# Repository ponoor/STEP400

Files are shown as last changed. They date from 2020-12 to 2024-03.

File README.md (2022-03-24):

## STEP400
STEP400

STEP400 is a 4-axis stepper motor driver designed for art or design projects. STEP400 combines the following elements into one single board:

- [Arduino Zero](https://www.arduino.cc/en/Guide/ArduinoZero)
- Ethernet shield
- Four stepper motor drivers
- Sensor inputs for homing and limiting

The [current firmware](https://github.com/ponoor/step-series-universal-firmware) is focused on working with [Open Sound Control](http://opensoundcontrol.org/) (OSC) via Ethernet, which is a common protocol for creative coding environments, like openFrameworks, Processing, Max, Unity, or Touch Designer.

Stepper driver chips are STMicroelectronics's [powerSTEP01](https://www.st.com/en/motor-drivers/powerstep01.html) which provide most of functionalities as a stepper driver.

Friend of STEP400 : [STEP800](https://github.com/ponoor/STEP800)

## Store
https://ponoor.com/en/shop/

## Documentation
https://ponoor.com/en/docs/step-series/

Forum: https://github.com/ponoor/step-series-support/discussions

## Repository Contents
### Firmware
**Important Note:**
The latest firmware is available at [STEP-series Universal Firmware](https://github.com/ponoor/step-series-universal-firmware) repository. Following directories and Releases are not maintained anymore. 

- [/STEP400_firmware](https://github.com/ponoor/STEP400/tree/master/STEP400_firmware) : Arduino Sketch folder
- [/firmware-platformio/STEP400_firmware](https://github.com/ponoor/STEP400/tree/master/firmware-platformio/STEP400_firmware) : PlatformIO folder

### Hardware
[/hardware](https://github.com/ponoor/STEP400/tree/master/hardware) : Eagle design files, BOM lists, and schematics PDFs

### Others
[/configTool](https://github.com/ponoor/STEP400/tree/master/configTool) : The configuration tool consists of a html and JavaScritpts.

## Firmware dependency
- **[OSC Library](https://github.com/CNMAT/OSC)** from CNMAT
- **[Ponoor PowerSTEP01 Library](https://github.com/ponoor/Ponoor_PowerSTEP01_Library)**
- **[ArduinoJSON Library](https://arduinojson.org/)**
- **[Adafruit SleepyDog Arduino Library](https://github.com/adafruit/Adafruit_SleepyDog)**

## Examples
### Max
https://github.com/ponoor/step-series-example-Max

### Processing
https://github.com/yuskegoto/STEP400_Processing

Contribution of [@yuskegoto](https://github.com/yuskegoto)

### openFrameworks
https://github.com/ponoor/step-series-example-openFrameworks

Contribution of [@niimi](https://github.com/niimi)

### Unity
https://github.com/ponoor/step-series-example-Unity

Contribution of [@niimi](https://github.com/niimi)

### TouchDesigner
https://github.com/ponoor/step-series-example-TouchDesigner

Contribution of [@loveandsheep](https://github.com/loveandsheep) and [@yuskegoto](https://github.com/yuskegoto)

### Node-RED
https://github.com/yuskegoto/STEP400_Node-RED

Contribution of [@yuskegoto](https://github.com/yuskegoto)

### Python library
https://github.com/ponoor/python-step-series

Contribution of [@JulianOrteil](https://github.com/JulianOrteil)

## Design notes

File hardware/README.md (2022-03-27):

# Diagram
```mermaid
flowchart LR
	MCU ---|SPI/SERCOM4| W5500 --- Ethernet
	MCU --- |SPI/SERCOM3|PowerSTEP01 --> Motor
	HomeSw -->|SW| PowerSTEP01
	LimitSw -->|ADCIN| PowerSTEP01
	DIPSW --> MCU
	MCU --> Brake
  ```
  
  Check the [document](https://ponoor.com/en/docs/step-series/technical-information/hardware-step400/) for details.

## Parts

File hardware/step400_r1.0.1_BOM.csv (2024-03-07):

# | Name | Value | Description | Package | Manufacture | Manufacturer Part Number | Designator | Qty | Type
1 | SMD-LED | GREEN | general LED green | LED-0603 | Lite-On | LTST-C193TGKT-5A | 3.3V, BUSY1, BUSY2, BUSY3, BUSY4 | 5 | SMD
2 | MLCC | 4.7uF/100V | 4.7uF / 20% / 100V / X5R | C1210 | Taiyo Yuden | HMK325C7475KMHPE | C1, C2 | 2 | SMD |  | updated
3 | MLCC | 47uF/6.3V | 47uF / 20% / 6.3V / X5R | C1206 | Samsung Electro-Mechanics | CL31A476MQHNNNE | C11, C12, C25, C26 | 4 | SMD |  | updated
4 | MLCC | 10uF/10V | 10uF / 20% / 10V / X5R | C0805 | Samsung Electro-Mechanics | CL21A106KOQNNNG | C14 | 1 | SMD
5 | MLCC | 1uF/6.3V | 1uF / 20% / 6.3V / X5R | C0603 | Samsung Electro-Mechanics | CL10A105KO8NNNC | C17, C18, C19, C20, C39, C40, C69, C70 | 8 | SMD
6 | MLCC | 4.7uF/6.3V | 4.7uF / 20% / 6.3V / X5R | C0603 | Samsung Electro-Mechanics | CL10A475KQ8NNNC | C29 | 1 | SMD
7 | MLCC | 100nF/100V | 100nF / 20% / 100V / X5R | C0805 | Samsung Electro-Mechanics | CL21B104KCFNNNE | C3, C57, C58, C87, C88 | 5 | SMD
8 | MLCC | 10nF/25V | 10nF / 20% / 25V / X5R | C0402 | Walsin Tech Corp | 0402B103K250 | C30, C35 | 2 | SMD
9 | MLCC | 22nF 50V | 22nF / 20% / 50V / X5R | C0402 | Walsin Tech Corp | 0402F223Z500CT | C34 | 1 | SMD
10 | MLCC | 6.8nF/25V | 6.8nF / 20% / 25V / X5R | C0402 | Walsin Tech Corp | 0402B682K500CT | C36, C37 | 2 | SMD
11 | MLCC | 100nF/50V | 100nF / 20% / 50V / X5R | C0603 | Walsin Tech Corp | 0603B104K500CT | C4, C8 | 2 | SMD
12 | MLCC | 47nF/50V | 47nF / 20% / 50V / X5R | C0805 | YAGEO | CC0805KRX7R9BB473 | C41, C42, C71, C72 | 4 | SMD |  | updated
13 | MLCC | 220nF/100V | 220nF / 20% / 100V / X5R | C0805 | YAGEO | CC0805KKX7R0BB224 | C43, C44, C47, C48, C49, C50, C51, C53, C73, C74, C77, C78, C79, C80, C81, C83 | 16 | SMD |  | updated
14 | MLCC | 100nF / 25V | 100nF / 20% / 25V / X5R | C0402 | Samsung Electro-Mechanics | CL05A104KA5NNNC | C5, C9, C10, C13, C15, C16, C21, C22, C23, C24, C27, C28, C31, C38, C45, C46, C55, C56, C75, C76, C85, C86 | 22 | SMD |  | updated
15 | MLCC | 470nF/25V | 470nF / 20% / 25V / X5R | C0603 | Samsung Electro-Mechanics | CL10B474KA8NNNC | C52, C54, C61, C62, C82, C84, C91, C92 | 8 | SMD
16 | Chemical Capacitor | 100uF/100V | 100uF / 20% / 100V | E5-10,5 | Rubycon | 100PX100MEFC10X16 | C59, C60, C63, C64, C89, C90, C93, C94 | 8 | THT
17 | MLCC | 22pF/50V | 22pF / 10% / 50V / X5R | C0402 | Walsin Tech Corp | 0402N220J500 | C6, C7, C32, C33 | 4 | SMD
18 | MLCC | 220nF/6.3V | 220nF / 20% / 6.3V / X5R | C0402 | YAGEO | CC0402KRX5R5BB224 | C65, C66, C95, C96 | 4 | SMD |  | updated
19 | MLCC | 22uF/6.3V | 22uF / 20% / 6.3V / X5R | C0805 | Samsung Electro-Mechanics | CL21A226MQQNNNE | C67, C68, C97, C98 | 4 | SMD
20 | Shrouded header | 2.5mm, 3P | B3B-XASK-1 | B3B-XASK-1 | JST | B03B-XASK-1(LF)(SN) | CN1, CN2, CN3, CN4, CN5, CN6, CN9, CN10 | 8 | THT
21 | Shrouded header | 2.5mm, 4P | B4B-XASK-1 | B4B-XASK-1 | JST | B04B-XASK-1(LF)(SN) | CN7, CN8, CN11, CN12 | 4 | THT | NO mount
22 | Zener Diode | 5.6V, 300mW | 5.6V ±7% 300mW | SOD-323 | ON Semiconductor | MM3Z5V6T1G | D1 | 1 | SMD
23 | Schottky diode | 100V 2A | 100V, 2A | DO-214AC | Guangdong Hottech | SS210A | D2 | 1 | SMD
24 | Switching diode array | BAR43 | 30V, 100mA | SOT23-3 | STMicroelectronics | BAR43SFILM | D3, D4, D5, D6 | 4 | SMD
25 | SMD-LED | Red | general LED red | LED-0603 | Lite-On | LTST-C193KRKT-5A | FLAG1, FLAG2, FLAG3, FLAG4, TX | 5 | SMD
26 | Ethernet Controller |  |  | TQFP48 | WIZnet | W5500 | IC1 | 1 | SMD
27 | DIP Switch |  | 8 digits | 2.54mm pitch SMD | kangshen | DSIC08LSGET | ID | 1 | SMD |  | updated
28 | DC Power receptacle |  | DC Power Receptacle Jack 5A 2.0mm 6.2mm | POWERJACK_SLOT | XKB Connectivity | DC-005-5A-2.0 | J1 | 1 | SMD
29 | Micro SD card slot |  |  |  | XUNPU | TF-115K | J2 | 1 | SMD
30 | 3.81mm 4pin header |  |  |  | Ningbo Kangnex Elec | WJ15EDGVC-3.81-4P | J3, J4, J5, J6 | 4 | THT
31 | Box header |  | Header 6P 0.100"(2.54mm) 2 | 61200621621 | Ckmtw(Shenzhen Cankemeng) | C132438 | J7 | 1 | THT
32 | SMD-LED | Orange | general LED orange | LED-0603 | Lite-On | LTST-C191KFKT | L | 1 | SMD
33 | Power Inductor | 15uH | ±20% 1.9A | L5050 | cjiang (Changjiang Microelectronics Tech) | FNR5040S150MT | L1 | 1 | SMD |  | updated
34 | Ferrite Beads | 330R-1500MA | 330Ω @ 100MHz 1.5A | L0805 | Murata Electronics | BLM21PG331SN1D | L2, L3 | 2 | SMD
35 | P-MOSFET |  | 100V 46A | D-PAK(TO252AA) | Winsok Semicon | WSF45P10 | Q1 | 1 | SMD
36 | Crystal Resonators | 32.768kHz | CRYSTAL | SMD-3215_2P | Seiko | SC-32S32.768kHz20PPM6pF | Q2 | 1 | SMD |  | updated
37 | Crystal Oscillator |  | 16MHz ±100ppm 3.3V | SG5032 | Shenzhen SCTF Elec | S5D16.000000B20F30T | Q3 | 1 | SMD |  | updated
38 | Chip Resistor | 100k | 5% 1/10W | R0603 | YAGEO | RC0603JR-07100KL | R1 | 1 | SMD
39 | Chip Resistor | 12.4K | 1％ 1/10W | R0603 | BOURNS | CR0603-FX-1242ELF | R11 | 1 | SMD |  | updated
40 | Chip Resistor | 1M 1/10W | 5% 1/10W | R0603 | YAGEO | AC0603JR-071ML | R13 | 1 | SMD
41 | Chip Resistor | 10R | 5% 1/10W | R0603 | YAGEO | RC0603JR-0710RL | R14 | 1 | SMD
42 | Chip Resistor | 330R | 5% 1/10W | R0603 | YAGEO | RC0603JR-07330RL | R15, R16 | 2 | SMD
43 | Chip Resistor | 0.1 | 1% 3W | R2512 | Bourns | CRA2512-FZ-R100ELF | R19, R20, R21, R22, R25, R26, R27, R28 | 8 | SMD
44 | Chip Resistor | 4.7k | 5% 1/10W | R0603 | YAGEO | AC0603JR-074K7L | R2 | 1 | SMD
45 | Chip Resistor | 5.1k | ±0.5% 0.1W | R0603 | YAGEO | RC0603FR-075K1L | R29, R30 | 2 | SMD
46 | Chip Resistor | 13k | 1％ 1/10W | R0603 | YAGEO | RC0603FR-0713KL | R3 | 1 | SMD
47 | Chip Resistor | 10K 1/10W | 5% 1/10W | R0603 | YAGEO | RC0603JR-0710KL | R4, R12, R31, R32, R33, R34 | 6 | SMD
48 | Chip Resistor | 3k | 1％ 1/10W | R0603 | YAGEO | RC0603FR-073KL | R5 | 1 | SMD
49 | Chip Resistor | 750 | 1％ 1/10W | R0603 | YAGEO | AC0603DR-07750RL | R6 | 1 | SMD
50 | Chip Resistor | 100R | 5% 1/10W | R0603 | YAGEO | RC0603JR-07100RL | R7, R8, R9, R10, R17, R18, R23, R24 | 8 | SMD
51 | Tactile Switch |  | SWITCH-SPST | 4.6x3.2 | ALPS Electric | SKRPABE010 | RESET | 1 | SMD
52 | Array Chip Resistor | 330 | 5% 1/16W | R0603 x4 | Bourns | CAY16-331J4LF | RN1, RN4, RN5 | 3 | SMD
53 | Array Chip Resistor | 33 | 5% 1/16W | R0603 x4 | Bourns | CAY16-330J4LF | RN2 | 1 | SMD
54 | Array Chip Resistor | 49.9 | 1% 1/16W | R0603 x4 | Bourns | CAY16-49R9F4LF | RN3 | 1 | SMD
55 | SMD-LED | Yellow | general LED yellow | LED-0603 | Lite-On | LTST-C191KSKT | RX | 1 | SMD
56 | Pin Header | 10 pin | Cortex Debug Connector | 1.27mm Pin Header 10P | Amphenol ICC | 20021121-00010C4LF | SWD | 1 | SMD
57 | TVS Diode Array | USBLC6-2SC6 | STMicroelectronics USBLC6 | SOT23-6L | STMicroelectronics | USBLC6-2SC6 | U1 | 1 | SMD
58 | DC-DC converter |  |  | HTSOP-J8 | ROHM | BD9G341AEFJ-E2 | U2 | 1 | SMD
59 | Voltage Regulator | LD1117S33 | 3.3V 0.8A | SOT223 | STMicroelectronics | LD1117S33TR | U3 | 1 | SMD
60 | MCU |  |  | TQFP-48 | Microchip | ATSAMD21G18A-AU | U4 | 1 | SMD
61 | Stepper Motor Driver |  |  | VFQFPN89 | STMicroelectronics | POWERSTEP01TR | U5, U6, U7, U8 | 4 | SMD
62 | USB Type C Connector |  | USB - Type C Female 16 SMT | USB-C_USB2.0-TYPE-C | XKB Connectivity | U262-161N-4BVC11 | USB1 | 1 | THT
63 | Barrier Terminal Block | 7.62mm, 2P |  | 7.62mm | Ningbo Kangnex Elec | WJ25C-B-7.62-2P | X1 | 1 | SMD
64 | Crystal Resonators | 25MHz | 25MHz ±20ppm12pF | CRYSTAL-3225 | Yangxing Tech | X322525MOB4SI | X2 | 1 | SMD |  | updated
65 | RJ45 Jack with Magnetics |  |  |  | Hanrun | HR871181A | X3 | 1 | THT

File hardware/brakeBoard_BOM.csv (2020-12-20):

# | Name | Value | Description | Package | Manufacture | MPN | Designator | Qty | Type
1 | SMD-LED | Red | general LED red | LED-0603 | Lite-On | LTST-C193KRKT-5A | D1, D10, D11, D12, D13 | 5 | SMD
2 | Schottky diode | 100V 2A |  | DO-214AC | Guangdong Hottech | SS210A | D2, D3, D4, D5, D6, D7, D8, D9 | 8 | SMD
3 | DC Power receptacle |  | DC Power Receptacle Jack 5A 2.0mm 6.2mm |  | XKB Connectivity | DC-005-5A-2.0 | J1 | 1 | THT
4 | PCB Header | 2P, Vertical | WR-TBL Serie 321 - 3.81 mm Vertical PCB Header | P=3.81mm | Ningbo Kangnex Elec | WJ15EDGVC-3.81-2P | J2, J3, J4, J5, J6 | 5 | THT
5 | Box header |  | Header 6P 0.100"(2.54mm) 2 | 61200621621 | Ckmtw(Shenzhen Cankemeng) | C132438 | J7 | 1 | THT
6 | N-MOSFET |  | 60V 28A(Tc) 3V @ 250uA 40mΩ @ 12A,10V | TO-252-2(DPAK) | Winsok Semicon | WSF28N06 | Q1, Q2, Q3, Q4 | 4 | SMD
7 | Chip Resistor | 5.6k | 5% 0.25W | R0805 | KOA Speer Elec | RK73B2ATTD562J | R1, R2, R3, R4, R5 | 5 | SMD
8 | Array Chip Resistor | 10 | 5% 1/16W | R0603 x4 | Bourns | CAY16-100J4LF | RN1 | 1 | SMD
9 | Array Chip Resistor | 10k | 5% 1/16W | R0603 x4 | Bourns | CAY16-103J4LF | RN2 | 1 | SMD

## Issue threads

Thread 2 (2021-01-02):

[Docs] Tutorial

kanta, 2021-01-02:
https://ponoor.com/en/docs/step400/tutorial/
プロトタイプからコネクタが変更になったことに合わせて、日本語版で下記部分を変更しました。また僕のほうで英文を入れてみています。

旧
STEP400の電源コネクタは大容量の電源を接続することを想定していますが、小さなモータを回す場合は下の写真のような変換コネクタを使ってACアダプタを接続すると便利です。このコネクタは電子パーツ店やAmazonなどで入手可能です。上の例に出てきたモータを1台回す場合は、ACアダプタの容量は24V1Aあれば十分です。

写真では両端に専用の端子を圧着して使っていますが、両端を剥いてはんだを流しただけの状態でも使用可能です。

新
上の例に出てきたモータを1台回す場合は、ACアダプタの容量は24V1Aあれば十分です。STEP400に接続可能なのは、外径5.5mm, 内径2.1mmでセンタープラスのACアダプタです。

If you want to run a single motor in the example above, the AC adapter’s capacity of 24V1A is sufficient. Applicable AC adapters are which have 5.5mm outer diameter / 2.1mm inner diameter / center positive connector.

そのほか、以下の英文を追加しています（堀尾訳、要修正です）。

To simplify this tutorial, we will assume that the PC and the board are connected peer to peer with Ethernet cable. You can of course also go through a network switch (NOT a router) instead. Routers can make things complicated when they have DHCP functionality, not recommended to get started.

You can set individual KVALs for example with `/setRunKval` for `KVAL_RUN` but we are going to try following command which can set 4 KVALs at once.

kanta, 2021-01-02:
とりあえず上記の文章は、未チェック英文のメモです！

yuskegoto, 2021-01-18:
DCバレルジャック／プラグは英語でもDC barrel jack / plug なので、そのようにしては。またApplicableはあまり自然はない気がしますので power supply must have .... としてみました。以下のような感じでいかがでしょうか？
If you want to run a single motor in the example above, the AC adapter’s capacity of 24V1A is sufficient. **The power supply** must have **DC barrel plug** with 5.5mm outer diameter / 2.1mm inner diameter / center positive.

kanta, 2021-01-18:
ありがとうございます！更新しました。
https://ponoor.com/en/docs/step400/tutorial/

Closed 2021-04-10.

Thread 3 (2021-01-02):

[Docs] Power supply and Motor

kanta, 2021-01-02:
旧
ターミナルには4つのねじ式端子があり、左手の2個がマイナス、右手の2個がプラスの端子です。

新
STEP400にはDCジャック(4)と、ねじ式端子(5)の2種類の電源端子があります。
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
DCジャックは
- 外径5.5mm
- 内径2.1mm
- センタープラス

のコネクタが適合します。DCジャックの定格は24V5Aです。それを超える電圧および電流で使用する場合は、ねじ式ターミナルを使用してください。

ねじ式ターミナルは、基板端面から見て左がマイナス、右側がプラスの端子です。各端子のねじ径はM3です。直接ケーブルの芯線を締めこむこともできますが、専用の端子を使うとより確実に接続できます。

---

There are 2 types of power input ternaminals on STEP400, a DC jack (4) and a screw terminal(5).
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

For the DC jack, a connector which has
- 5.5mm outer diameter
- 2.1mm inner diameter
- center positive

will be applicable. The rateing of the DC jack are limited to 24V/5A. Use the screw terminal if you want to apply bigger voltage or current than that.

For the screw terminal, if you see the connector from the edge of the board, left side is negative, right side is positive terminal. The screw diameter is M3. You can fasten the cupper wire directly, but you can also use a dedicated terminal for a more secure connection.

yuskegoto, 2021-01-18:
以下のようにしてはいかがでしょうか？
For the DC barrel plug, use a DC barrel plug with following specifications

- 5.5mm outer diameter
- 2.1mm inner diameter
- center positive

The rating of the DC jack are limited to 24V/5A. Use the screw terminal if you want to supply larger voltage or current.

kanta, 2021-01-18:
こちらも #2 でご指摘いただいた部分のバリエーションですね。こういう細かな部分まで見ていただいてとても助かります！ありがとうございます。こちらもアップデートしましたー。

Closed 2021-04-10.

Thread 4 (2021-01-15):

[Docs] 電流モード、電圧モードを切り替えるコマンドがない

kanta, 2021-01-15:
[KVALとTVAL](https://ponoor.com/docs/step400/osc-command-reference/kval-and-tval/) というページに追記して、「電圧モードと電流モード」などに改題し要と思います。

kanta, 2021-01-15:
更新しました。
https://ponoor.com/docs/step400/functional-description/voltage-mode-and-current-mode/
https://ponoor.com/en/docs/step400/osc-command-reference/kval-and-tval/

Closed 2021-01-18.

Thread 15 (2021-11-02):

Python Library for Ponoor

JulianOrteil, 2021-11-02:
Good day @kanta and other maintainers/contributors of this project.

I must give my thanks and appreciation for developing such a project as this. Recently, I have purchased a STEP400 motor controller for a small project of mine; however, I did notice a lack of a library for interfacing with this device--specifically in Python. As my program is written entirely in Python, would you be opposed to me developing a library for this device? I plan on it doing nothing more than presenting your OSC endpoints (like `/getVersion`) in a Pythonic interface.

I am specifically asking for permission to use the name "ponoor" in it (like "python-ponoor", or "ponoor-step400, "ponoor-step800", etc).

Please do let me know your thoughts or concerns.
Jules

kanta, 2021-11-03:
Hi @JulianOrteil , that would be amazing! I haven't used Python much personally, but I can see how it could be a useful library for many users!
For the name, "Ponoor" is a name of a company so there are possibilities to release another products in the future. How about "python-step-series"? I have used this name to some other repos.
https://github.com/ponoor/step-series-support

Thanks for your idea and choosing STEP400!
kanta

JulianOrteil, 2021-11-03:
Hey kanta, great to know you're on board!

I have absolutely no issue with using a name such as that.

Because this library would be specifically for your Step-series products, I believe it would be most appropriate if the library were to live under your 'ponoor' organization. If you're able, could you please create an empty repository with the "python-step-series" name you suggested, and give me full-contributor access to it?

If not, I have no problem with it living under my account.
Jules

kanta, 2021-11-03:
Sounds perfect for me! I will create the repo and invite you to edit.
I have a question. There are some coding example repos for step series like this;
https://github.com/ponoor/step-series-example-openFrameworks
What do you think would be an appropriate name for the new repository? `step-series-example-Python` or `step-series-library-Python`?

JulianOrteil, 2021-11-03:
Typically, in Python--as I'm sure other languages--you don't need to to specify your library as a library in the name. Also, when I see "example", I believe it to be just an example application that I can run, not an API.

At any rate, I think your first suggestion of `python-step-series` is perfect. You can see other examples of this naming scheme here: https://pypi.org/search/?q=python-&o=

kanta, 2021-11-03:
Ok! `python-step-series` seems to be the most appropriate name. I have just create it and invite you. Thank you very much for your contribution!
https://github.com/ponoor/python-step-series

JulianOrteil, 2021-11-03:
I will get started right away. :+1:

Closed 2021-11-03.

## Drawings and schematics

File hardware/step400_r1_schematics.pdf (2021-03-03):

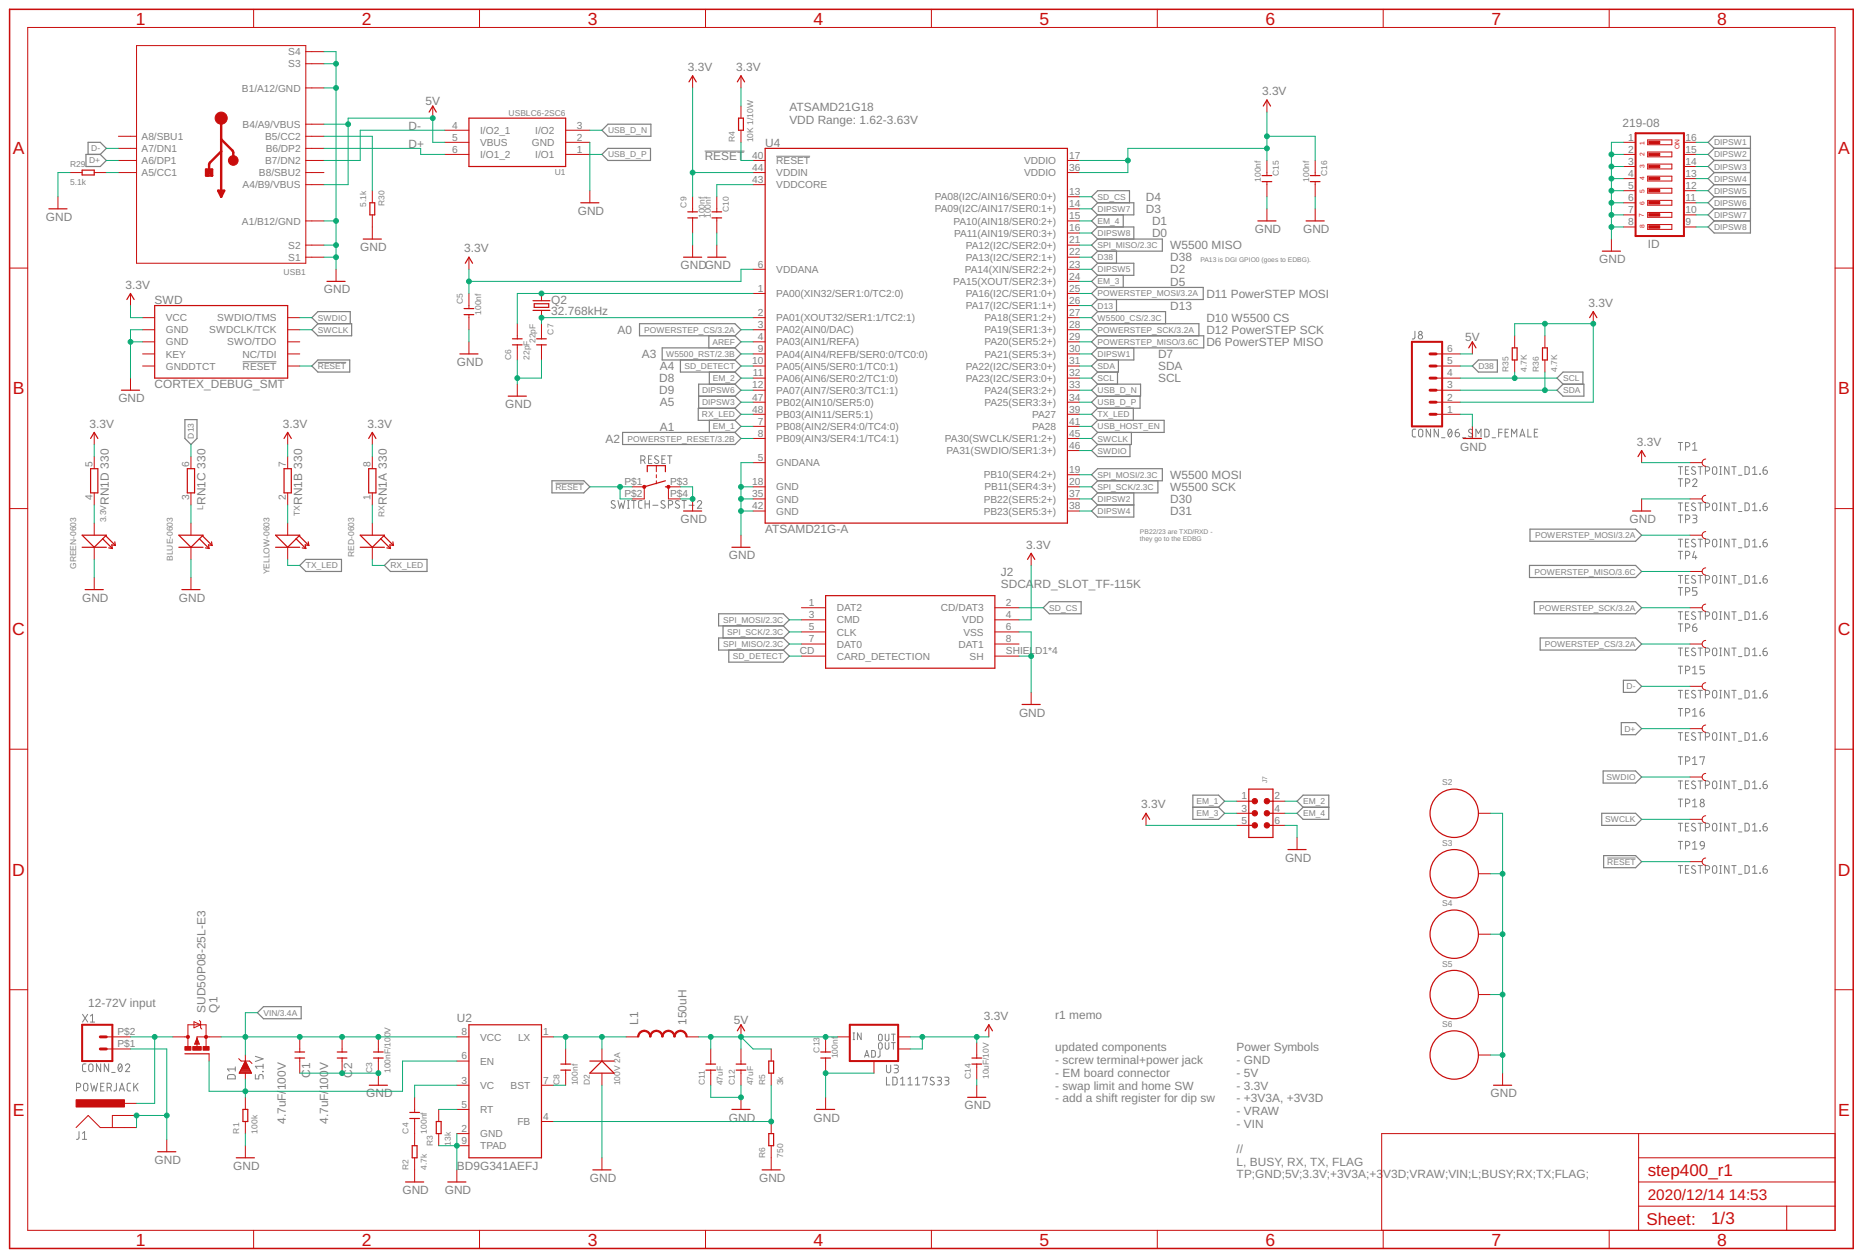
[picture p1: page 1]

4 | 13
5 | 12
6 | 11
7 | 10

PA13 is DGI GPIO0 (goes to EDBG).

PB22/23 are TXD/RXD -
they go to the EDBG

updated components
- screw terminal+power jack
- EM board connector
- swap limit and home SW
- add a shift register for dip sw

L, BUSY, RX, TX, FLAG
TP;GND;5V;3.3V;+3V3A;+3V3D;VRAW;VIN;L;BUSY;RX;TX;FLAG;

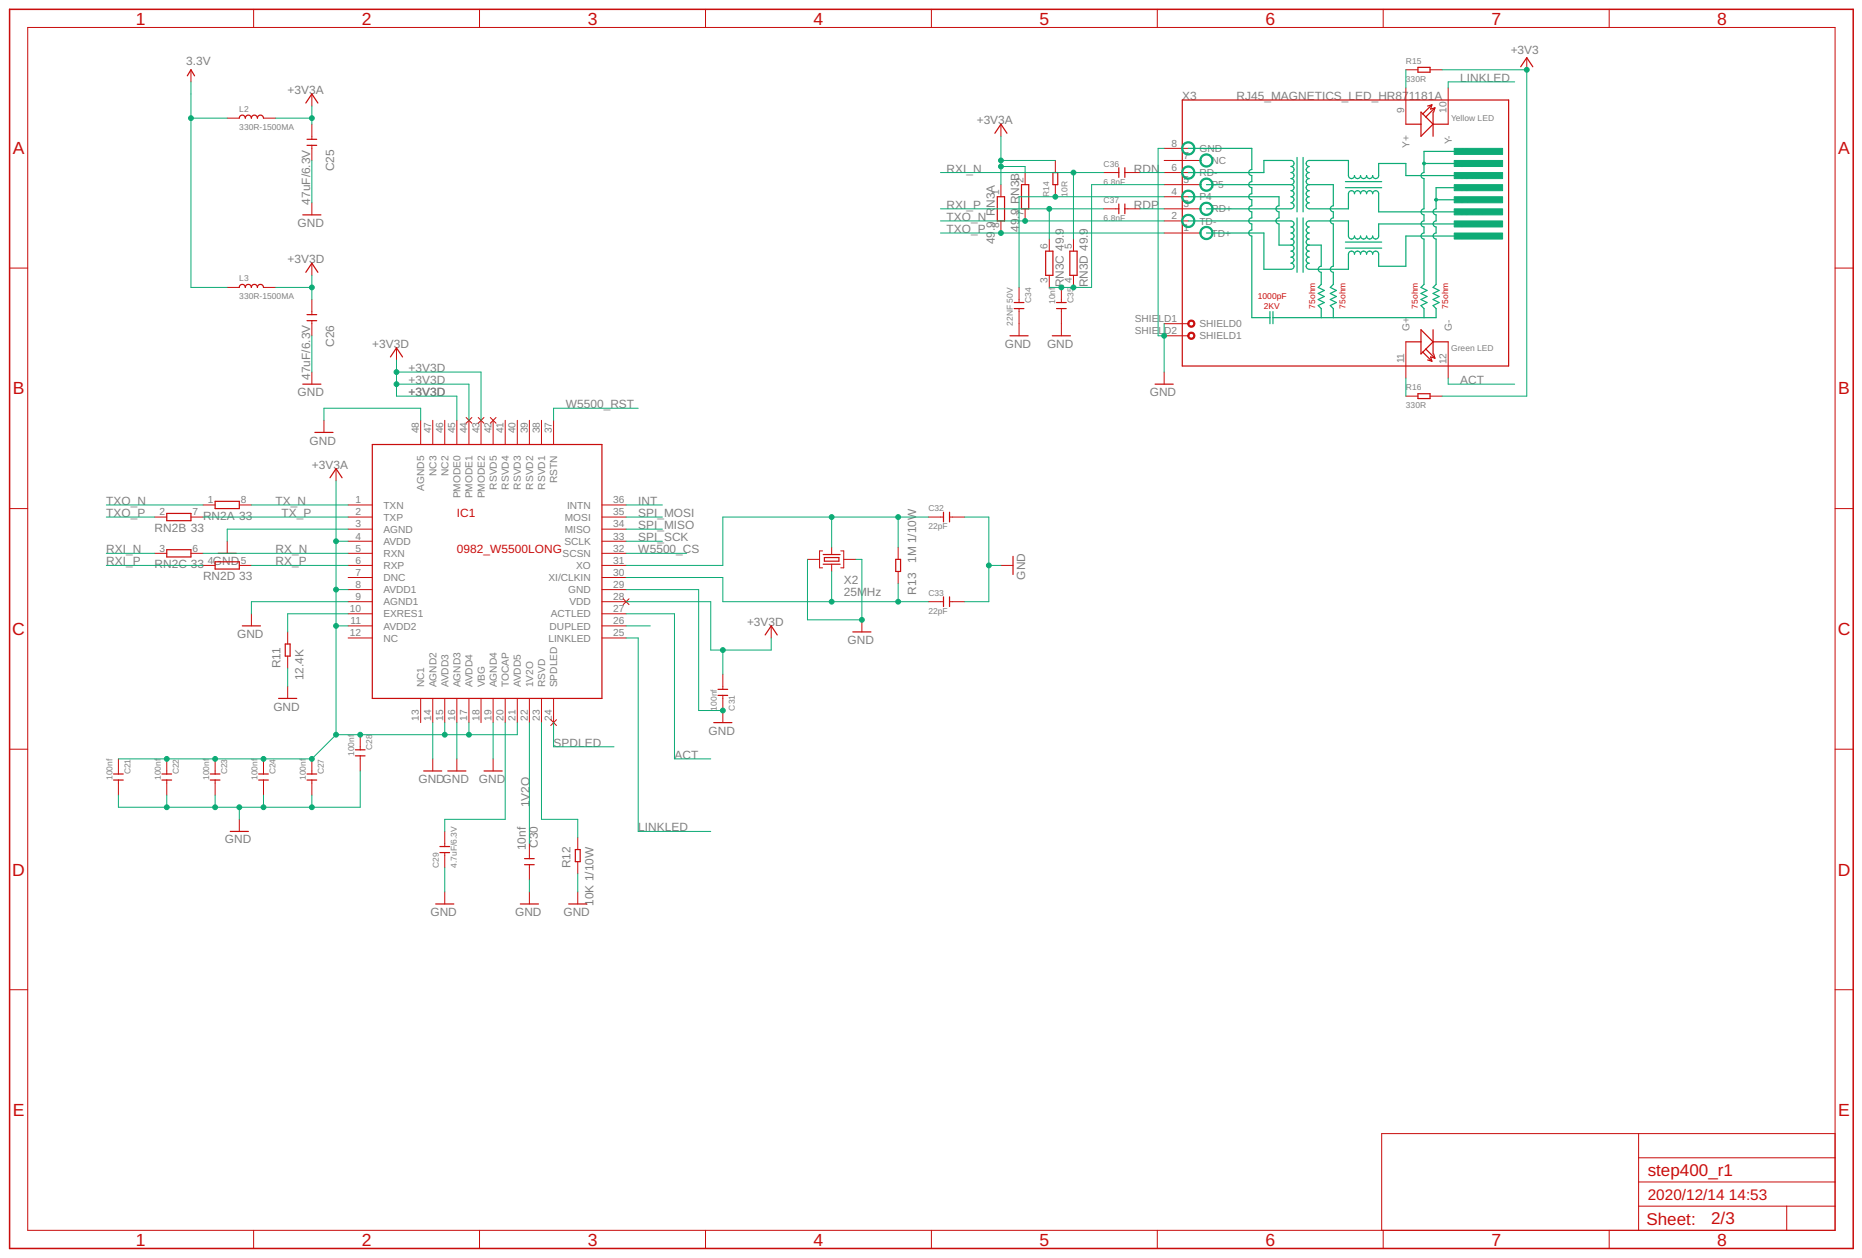
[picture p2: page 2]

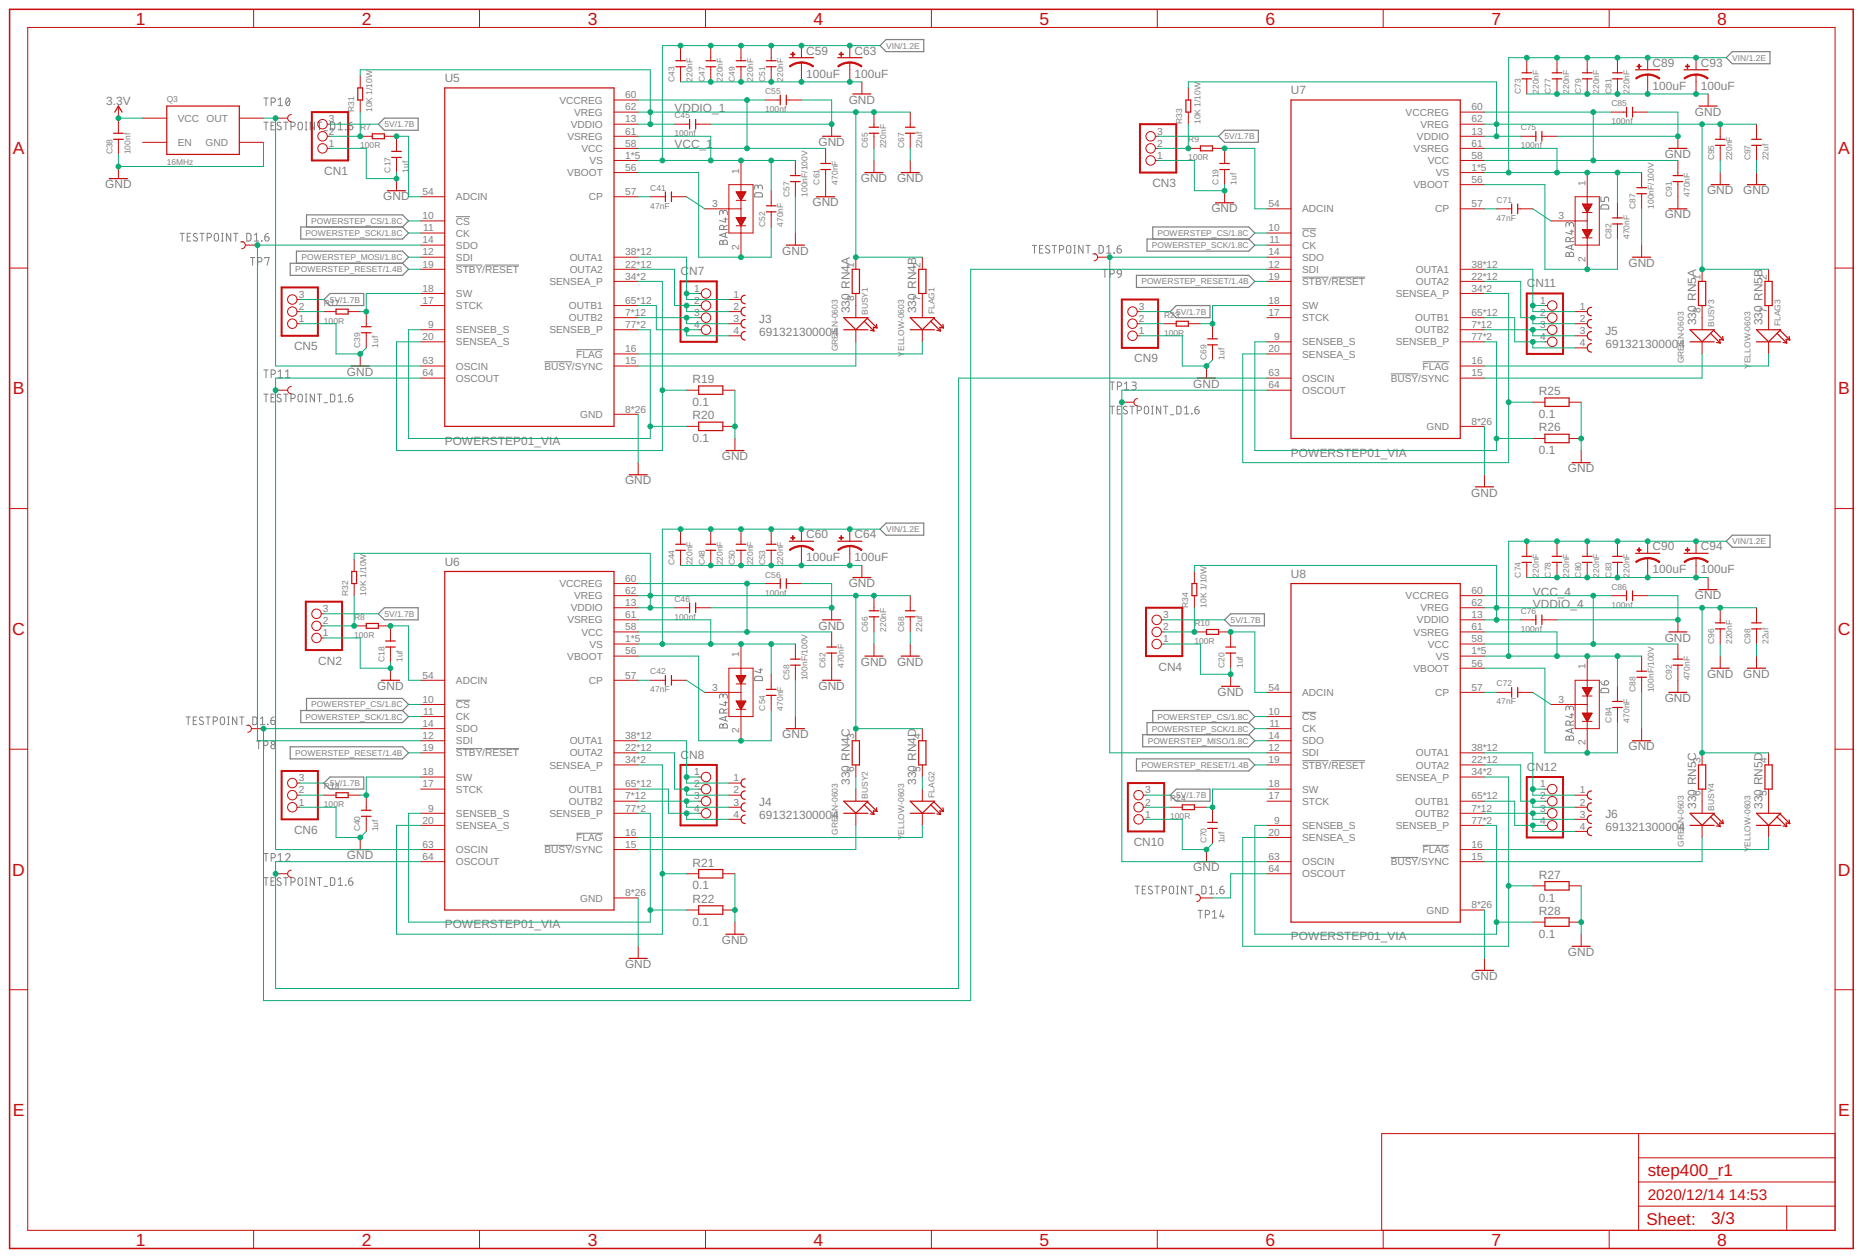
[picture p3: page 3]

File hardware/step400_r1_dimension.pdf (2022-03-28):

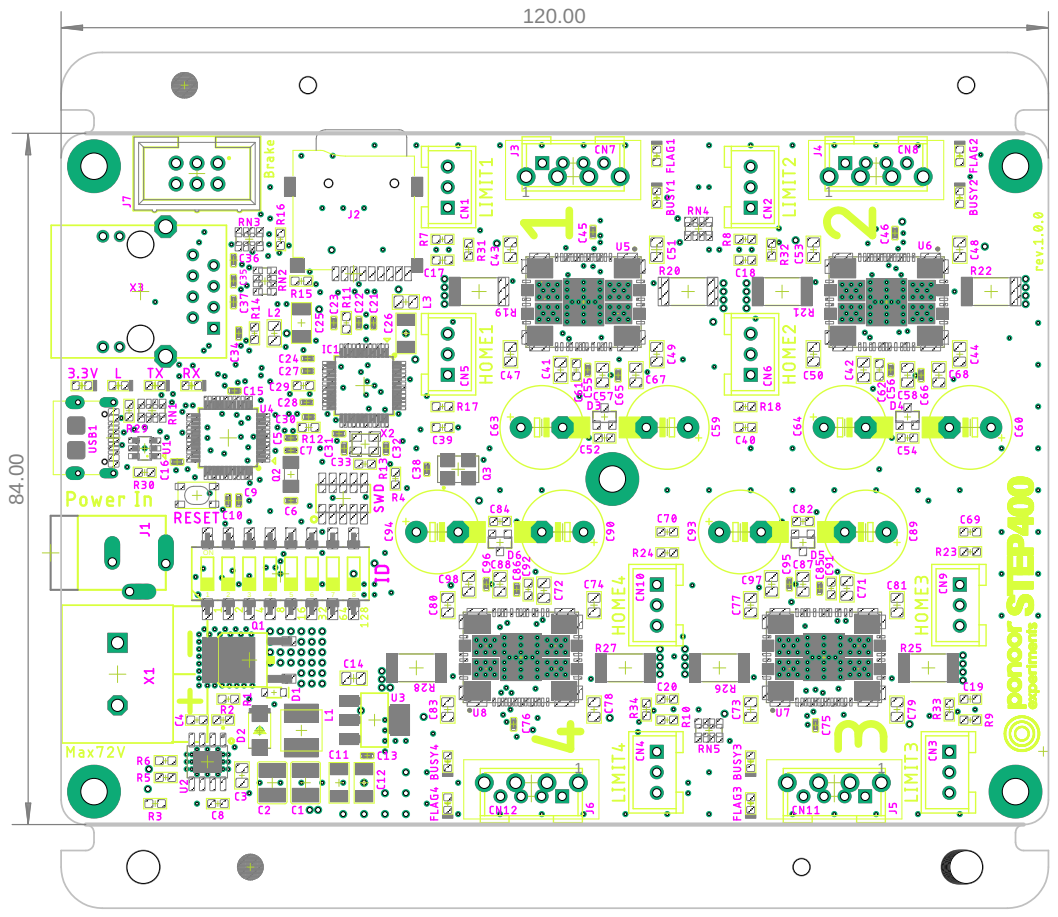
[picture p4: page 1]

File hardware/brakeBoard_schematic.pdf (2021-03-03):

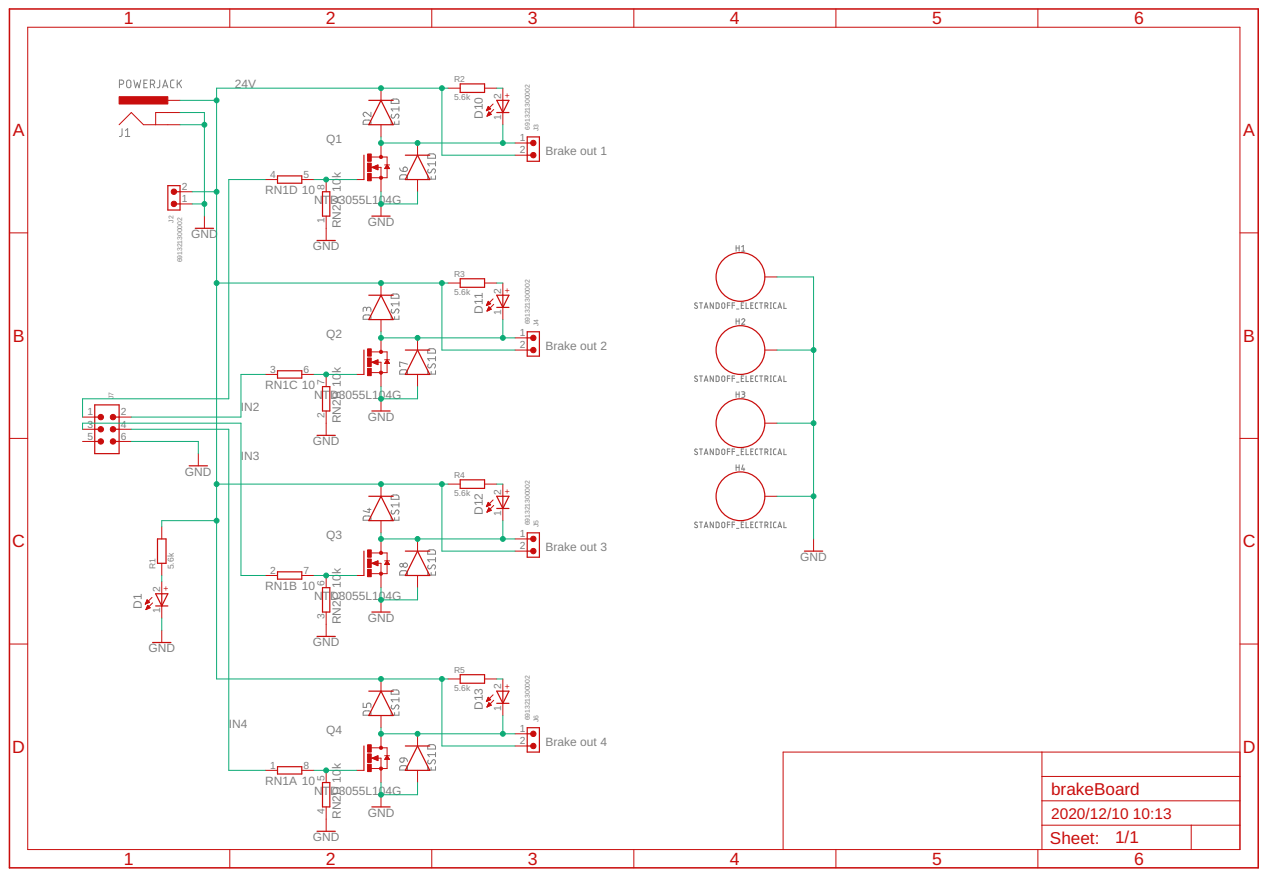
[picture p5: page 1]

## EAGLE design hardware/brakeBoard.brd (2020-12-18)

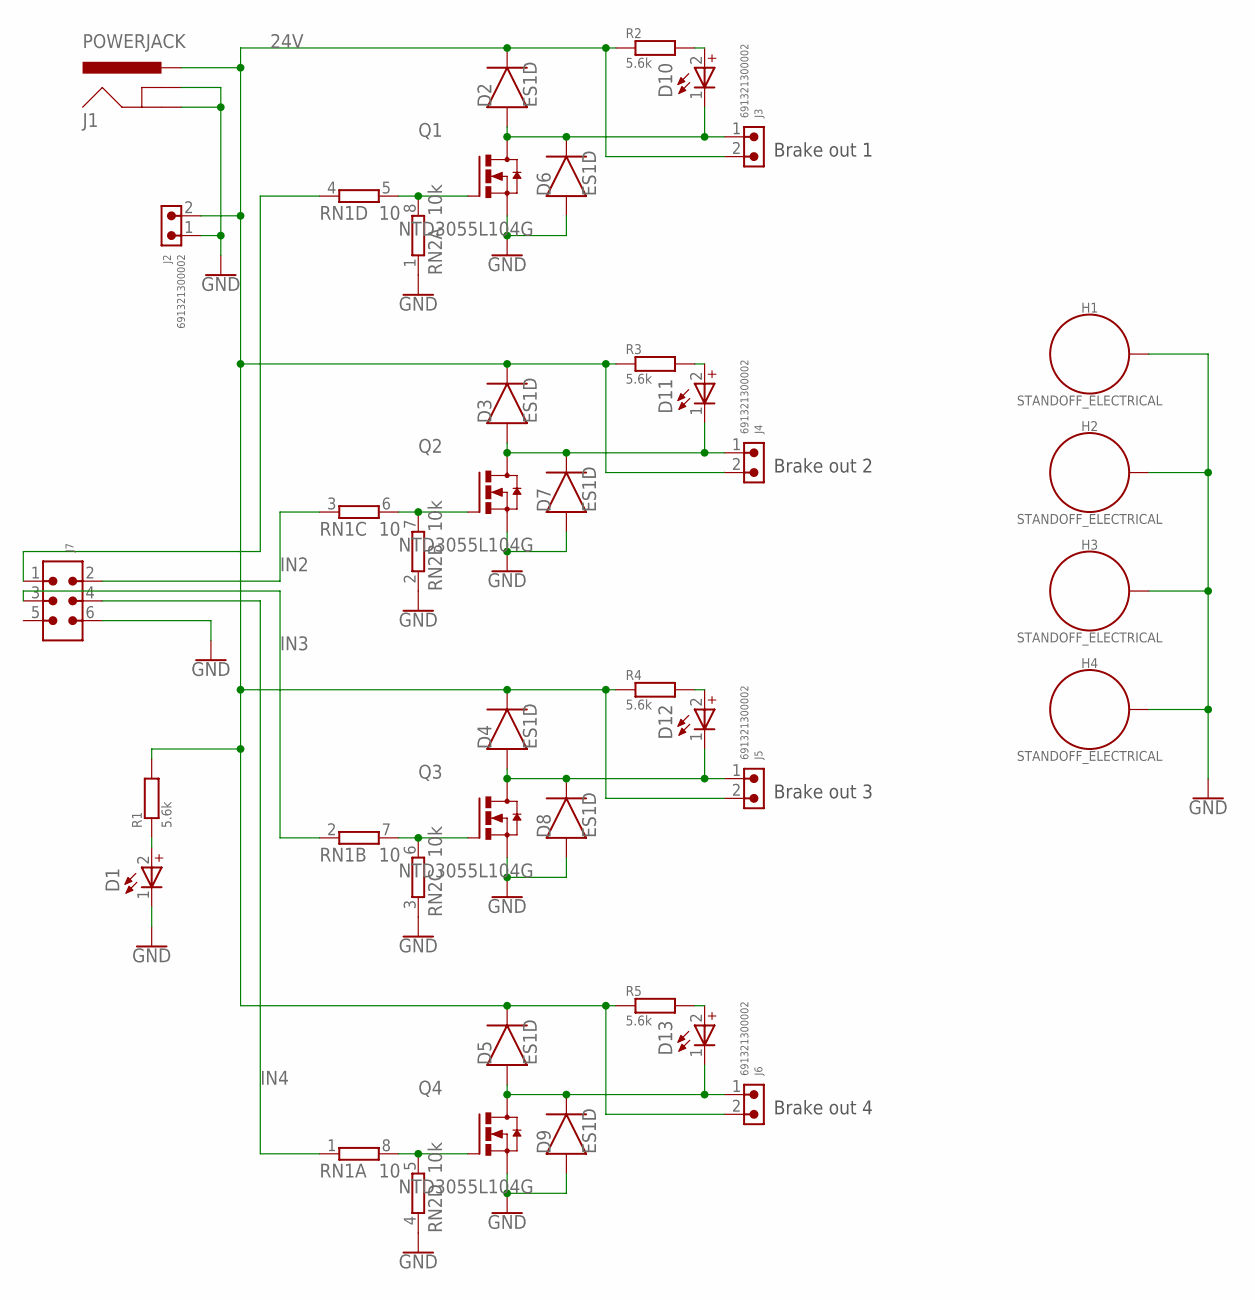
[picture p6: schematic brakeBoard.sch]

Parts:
D1, D10, D11, D12, D13: WL-SMCD_0603_150060GS55040; WL-SMCD_0603
D2, D3, D4, D5, D6, D7, D8, D9: ES1D; DIOM5226X290N
H1, H2, H3, H4: STANDOFF_ELECTRICAL; STANDOFF-ELECTRICAL
J1: POWERJACK; POWERJACK_SLOT
J2, J3, J4, J5, J6: 691321300002
J7: 6120XX21621_61200621621; 61200621621
Q1, Q2, Q3, Q4: NTD3055L104G; DPAK3
R1, R2, R3, R4, R5: 5.6k; RESC2012X65
RN1: 10; CAY16_LONG_W
RN2: 10k; CAY16_LONG_W

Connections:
24V: D2.1 (C), D3.1 (C), D4.1 (C), D5.1 (C), J1.P$2 (PWR), J1.P$3 (PWR), J1.P$4 (PWR), J1.P$5 (PWR), J1.P$6 (PWR), J1.P$7 (PWR), J1.P$8 (PWR), J1.P$9 (PWR), J1.P$10 (PWR), J1.P$11 (PWR), J1.P$12 (PWR), J1.P$13 (PWR), J1.P$14 (PWR), J1.P$15 (PWR), J1.P$16 (PWR), J1.P$17 (PWR), J1.P$18 (PWR), J1.P$19 (PWR), J1.P$20 (PWR), J1.P$21 (PWR), J1.P$22 (PWR), J1.P$23 (PWR), J1.P$24 (PWR), J1.P$25 (PWR), J1.P$26 (PWR), J1.P$27 (PWR), J1.P$28 (PWR), J2.2, J3.2, J4.2, J5.2, J6.2, R1.2, R2.1, R3.1, R4.1, R5.1
GND: D1.1 (_), D6.2 (A), D7.2 (A), D8.2 (A), D9.2 (A), H1.P1, H2.P1, H3.P1, H4.P1, J1.P$33 (GNDBREAK), J1.P$34 (GNDBREAK), J1.P$35 (GNDBREAK), J1.P$36 (GNDBREAK), J1.P$37 (GNDBREAK), J1.P$38 (GNDBREAK), J1.P$39 (GNDBREAK), J1.P$40 (GNDBREAK), J1.P$41 (GNDBREAK), J1.P$42 (GNDBREAK), J1.P$43 (GNDBREAK), J1.P$44 (GNDBREAK), J1.P$45 (GNDBREAK), J1.P$46 (GNDBREAK), J1.P$47 (GNDBREAK), J1.P$48 (GNDBREAK), J1.P$49 (GNDBREAK), J1.P$50 (GNDBREAK), J1.P$51 (GNDBREAK), J1.P$52 (GNDBREAK), J1.P$53 (GNDBREAK), J1.P$54 (GNDBREAK), J1.P$55 (GNDBREAK), J1.P$56 (GNDBREAK), J1.P$63 (GND), J1.P$64 (GND), J1.P$65 (GND), J1.P$66 (GND), J1.P$67 (GND), J1.P$68 (GND), J1.P$69 (GND), J1.P$70 (GND), J1.P$71 (GND), J1.P$72 (GND), J1.P$73 (GND), J1.P$74 (GND), J1.P$75 (GND), J1.P$76 (GND), J1.P$77 (GND), J1.P$78 (GND), J1.P$79 (GND), J1.P$80 (GND), J1.P$81 (GND), J1.P$82 (GND), J1.P$83 (GND), J1.P$84 (GND), J1.P$85 (GND), J2.1, J7.6, Q1.2 (S), Q2.2 (S), Q3.2 (S), Q4.2 (S), RN2.1, RN2.2 (1), RN2.3 (1), RN2.4 (1)
IN1: J7.1, RN1.4 (1)
IN2: J7.2, RN1.3 (1)
IN3: J7.3, RN1.2 (1)
IN4: J7.4, RN1.1
unnamed: D2.2 (A), D6.1 (C), D10.1 (_), J3.1, Q1.3 (D)
unnamed: D10.2 (+), R2.2
unnamed: Q1.1 (G), RN1.5 (2), RN2.8 (2)
unnamed: D3.2 (A), D7.1 (C), D11.1 (_), J4.1, Q2.3 (D)
unnamed: D11.2 (+), R3.2
unnamed: D4.2 (A), D8.1 (C), D12.1 (_), J5.1, Q3.3 (D)
unnamed: D12.2 (+), R4.2
unnamed: D5.2 (A), D9.1 (C), D13.1 (_), J6.1, Q4.3 (D)
unnamed: D13.2 (+), R5.2
unnamed: Q4.1 (G), RN1.8 (2), RN2.5 (2)
unnamed: Q3.1 (G), RN1.7 (2), RN2.6 (2)
unnamed: Q2.1 (G), RN1.6 (2), RN2.7 (2)
unnamed: D1.2 (+), R1.1

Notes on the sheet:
Brake out 1
Brake out 2
Brake out 3
Brake out 4

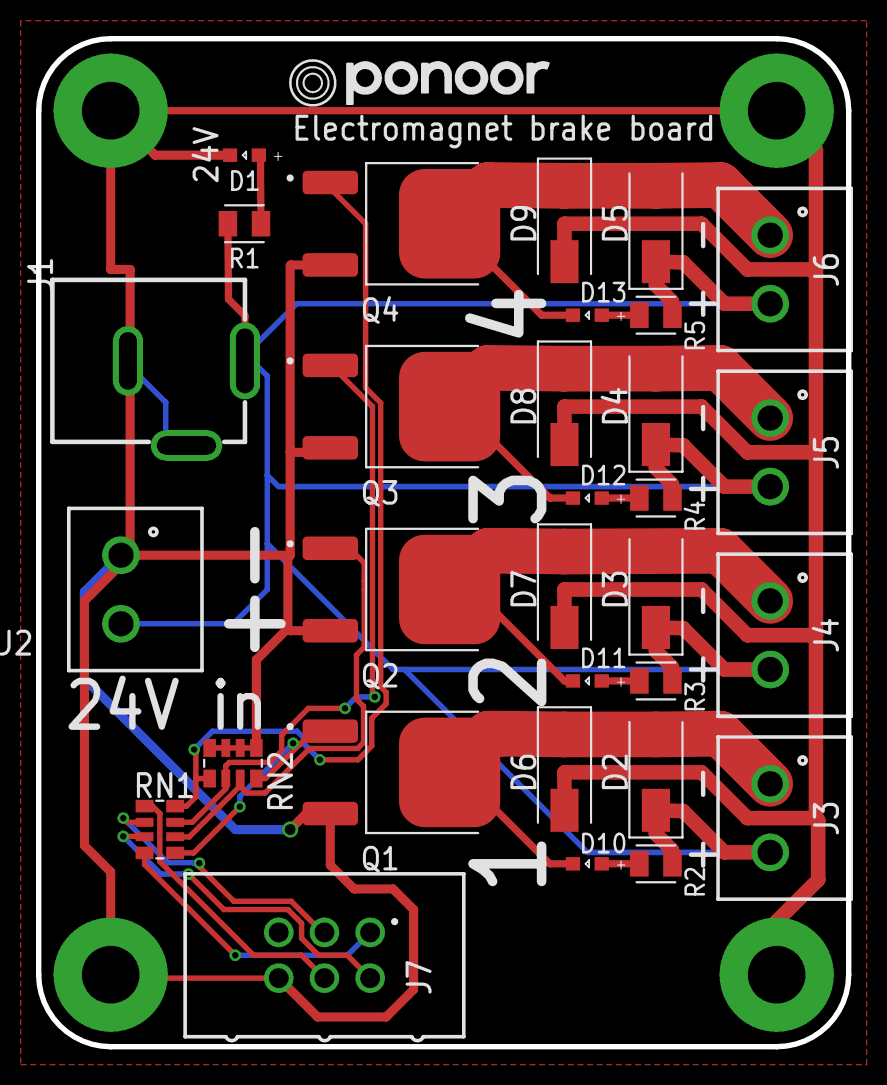
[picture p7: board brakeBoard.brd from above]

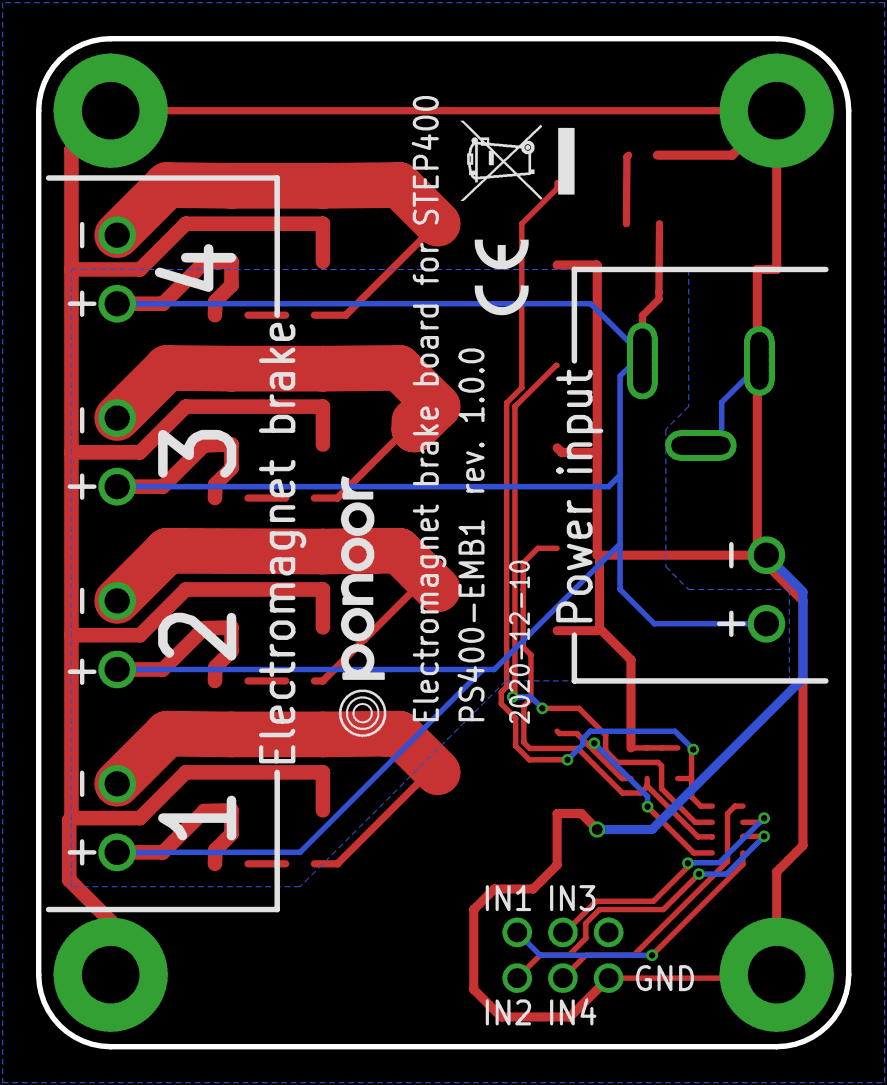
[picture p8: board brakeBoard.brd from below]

Board: 2 copper layers, 45.0 x 56.0 mm, 39 parts (3 on the bottom side), 19 nets.

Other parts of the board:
U$2, U$3: PONOOR_TEXT_15MM
U$5: WEEE_6MM
U$6: CE_3MM

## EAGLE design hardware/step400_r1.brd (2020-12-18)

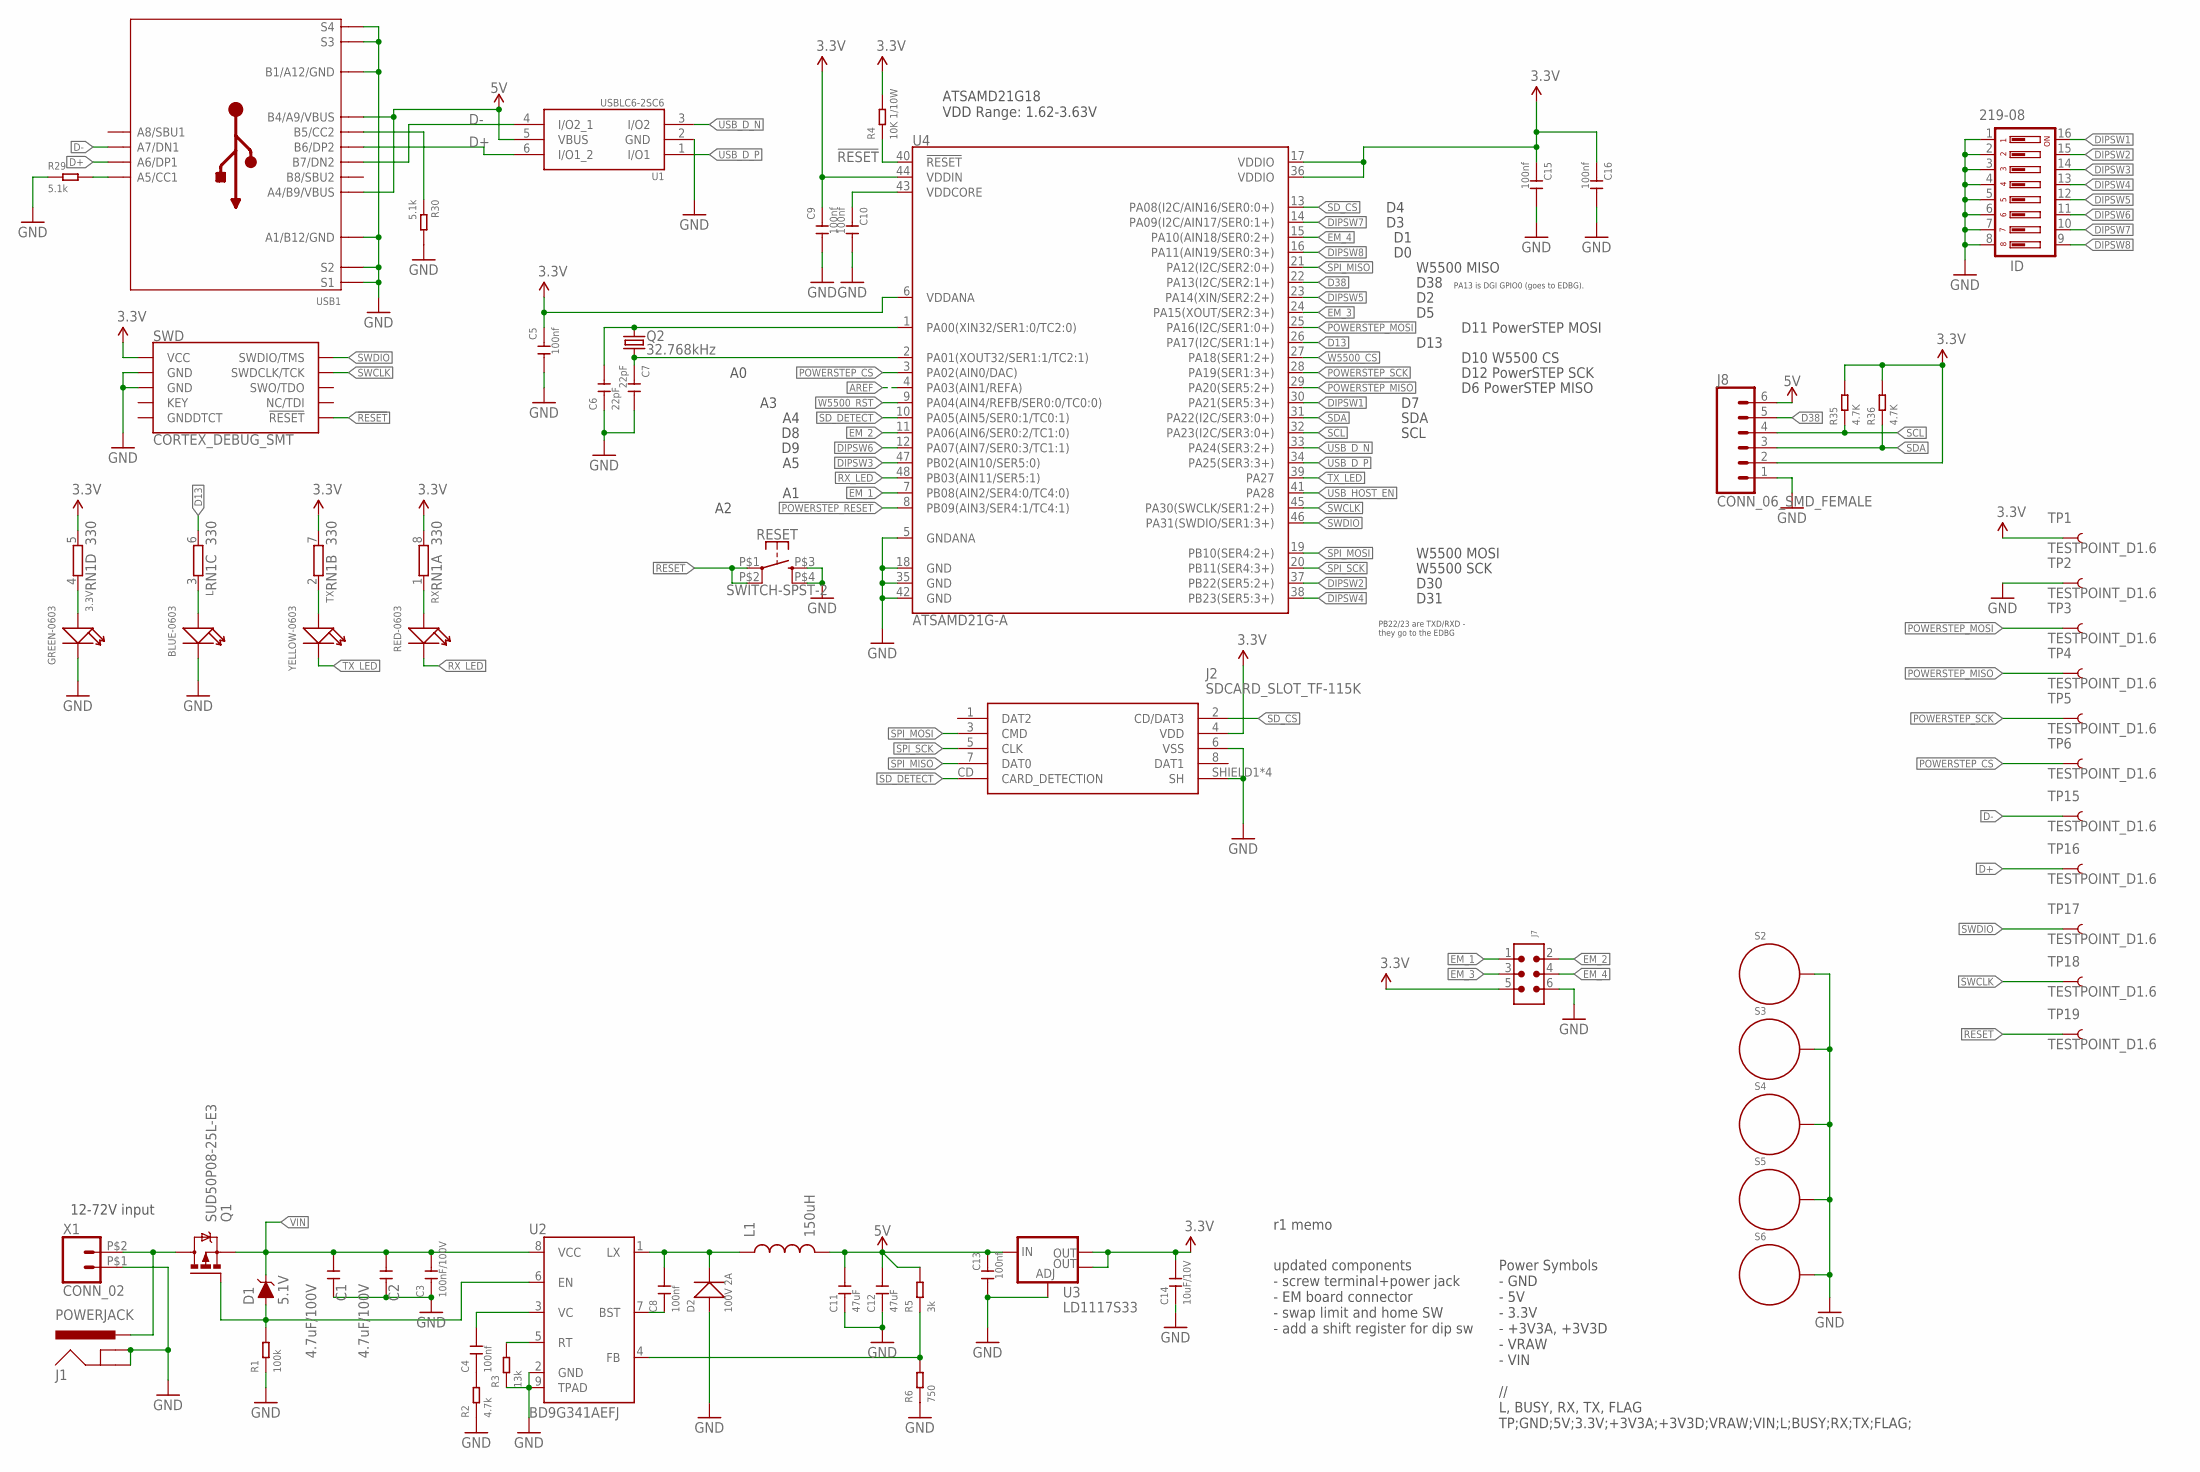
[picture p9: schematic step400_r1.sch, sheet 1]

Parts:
3.3V: GREEN-0603; LED-0603
C1, C2: 4.7uF/100V; C1210
C3: 100nF/100V; C0805
C4, C8: 100nf; C0603
C5, C9, C10, C13, C15, C16: 100nf; C0402
C6, C7: 22pF; C0402
C11, C12: 47uF; C1206
C14: 10uF/10V; C0805
D1: 5.1V; SOD-323
D2: 100V 2A; DO-214AC
ID: 219-08; CTS-219-08
J1: POWERJACK; POWERJACK_SLOT
J2: SDCARD_SLOT_TF-115K; TF-115K
J7: 6120XX21621_61200621621; 61200621621
J8: CONN_06_SMD_FEMALE; 1X06-SMD-FEMALE
L: BLUE-0603; LED-0603
L1: 150uH; L5045_L
Q1: SUD50P08-25L-E3; D-PAK_TO252AA
Q2: 32.768kHz; FC-135
R1: 100k; R0603
R2: 4.7k; R0603
R3: 13k; R0603
R4: 10K 1/10W; R0603
R5: 3k; R0603
R6: 750; R0603
R29, R30: 5.1k; R0603
R35, R36: 4.7K; R0603
RESET: SWITCH-SPST-2; SKRP
RN1: 330; CAY16_LONG_W
RX: RED-0603; LED-0603
S2, S3, S4, S5, S6: STANDOFF_ELECTRICAL; STANDOFF-ELECTRICAL
SWD: CORTEX_DEBUG_SMT; 20021121-00010C4LF
TP1, TP2, TP3, TP4, TP5, TP6, TP15, TP16, TP17, TP18, TP19: TESTPOINT_D1.6
TX: YELLOW-0603; LED-0603
U1: USBLC6-2SC6; SOT23-6L
U2: BD9G341AEFJ; SOIC127P600X100-9N
U3: LD1117S33; SOT223
U4: ATSAMD21G-A; TQFP-48
USB1: USB-C_USB2.0-TYPE-C
X1: CONN_02; WJ25C-B-7.62-2P

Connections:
3.3V: C5.1, C9.1, C14.2, C15.1, C16.1, J2.4 (VDD), J7.5, J8.2, R4.2, R35.2, R36.2, RN1.5 (2), RN1.7 (2), RN1.8 (2), SWD.P$1 (VCC), TP1.1, U3.2 (OUT), U3.4 (OUT), U4.6 (VDDANA), U4.17 (VDDIO), U4.36 (VDDIO), U4.44 (VDDIN); also elsewhere on the board
5V: C11.2, C12.2, C13.1, J8.6, L1.P$2 (2), R5.2, U1.5 (VBUS), U3.3 (IN), USB1.A4_B9 (A4/B9/VBUS), USB1.B4_A9 (B4/A9/VBUS); also elsewhere on the board
!RESET: R4.1, RESET.P$1 (1), RESET.P$2 (2), SWD.P$10 (!RESET), TP19.1, U4.40 (!RESET!)
AREF: U4.4 (PA03(AIN1/REFA))
D13: RN1.6 (2), U4.26 (PA17(I2C/SER1:1+))
D38: J8.5, U4.22 (PA13(I2C/SER2:1+))
D+: TP16.1, U1.6 (I/O1_2), USB1.A6 (A6/DP1), USB1.B6 (B6/DP2)
D-: TP15.1, U1.4 (I/O2_1), USB1.A7 (A7/DN1), USB1.B7 (B7/DN2)
DIPSW1: ID.16, U4.30 (PA21(SER5:3+))
DIPSW2: ID.15, U4.37 (PB22(SER5:2+))
DIPSW3: ID.14, U4.47 (PB02(AIN10/SER5:0))
DIPSW4: ID.13, U4.38 (PB23(SER5:3+))
DIPSW5: ID.12, U4.23 (PA14(XIN/SER2:2+))
DIPSW6: ID.11, U4.12 (PA07(AIN7/SER0:3/TC1:1))
DIPSW7: ID.10, U4.14 (PA09(I2C/AIN17/SER0:1+))
DIPSW8: ID.9, U4.16 (PA11(AIN19/SER0:3+))
EM_1: J7.1, U4.7 (PB08(AIN2/SER4:0/TC4:0))
EM_2: J7.2, U4.11 (PA06(AIN6/SER0:2/TC1:0))
EM_3: J7.3, U4.24 (PA15(XOUT/SER2:3+))
EM_4: J7.4, U4.15 (PA10(AIN18/SER0:2+))
GND: 3.3V.-, C1.2, C2.2, C3.1, C5.2, C6.1, C7.2, C9.2, C10.2, C11.1, C12.1, C13.2, C14.1, C15.2, C16.2, D2.1 (+), ID.1, ID.2, ID.3, ID.4, ID.5, ID.6, ID.7, ID.8, J1.P$33 (GNDBREAK), J1.P$34 (GNDBREAK), J1.P$35 (GNDBREAK), J1.P$36 (GNDBREAK), J1.P$37 (GNDBREAK), J1.P$38 (GNDBREAK), J1.P$39 (GNDBREAK), J1.P$40 (GNDBREAK), J1.P$41 (GNDBREAK), J1.P$42 (GNDBREAK), J1.P$43 (GNDBREAK), J1.P$44 (GNDBREAK), J1.P$45 (GNDBREAK), J1.P$46 (GNDBREAK), J1.P$47 (GNDBREAK), J1.P$48 (GNDBREAK), J1.P$49 (GNDBREAK), J1.P$50 (GNDBREAK), J1.P$51 (GNDBREAK), J1.P$52 (GNDBREAK), J1.P$53 (GNDBREAK), J1.P$54 (GNDBREAK), J1.P$55 (GNDBREAK), J1.P$56 (GNDBREAK), J1.P$63 (GND), J1.P$64 (GND), J1.P$65 (GND), J1.P$66 (GND), J1.P$67 (GND), J1.P$68 (GND), J1.P$69 (GND), J1.P$70 (GND), J1.P$71 (GND), J1.P$72 (GND), J1.P$73 (GND), J1.P$74 (GND), J1.P$75 (GND), J1.P$76 (GND), J1.P$77 (GND), J1.P$78 (GND), J1.P$79 (GND), J1.P$80 (GND), J1.P$81 (GND), J1.P$82 (GND), J1.P$83 (GND), J1.P$84 (GND), J1.P$85 (GND), J2.6 (VSS), J2.SHIELD1 (SH), J2.SHIELD2 (SH), J2.SHIELD3 (SH), J2.SHIELD4 (SH), J7.6, J8.1, L.-, R1.1, R2.1, R3.1, R6.1, R29.1, R30.2, RESET.P$3 (3), RESET.P$4 (4), S2.P1, S3.P1, S4.P1, S5.P1, S6.P1, SWD.P$3 (GND), SWD.P$5 (GND), TP2.1, U1.2 (GND), U2.2 (GND), U2.9 (TPAD), U3.1 (ADJ), U4.5 (GNDANA), U4.18 (GND), U4.35 (GND), U4.42 (GND), USB1.A1_B12 (A1/B12/GND), USB1.B1_A12 (B1/A12/GND), USB1.S7 (S1), USB1.S8 (S1), USB1.S9 (S1), USB1.S10 (S1), USB1.S11 (S1), USB1.S12 (S1), USB1.S13 (S1), USB1.S14 (S1), USB1.S15 (S1), USB1.S16 (S3), USB1.S17 (S3), USB1.S18 (S3), USB1.S19 (S3), USB1.S20 (S3), USB1.S21 (S3), USB1.S22 (S3), USB1.S23 (S3), USB1.S24 (S3), USB1.S25 (S3), USB1.S26 (S3), USB1.S27 (S3), USB1.S29 (S2), USB1.S30 (S2), USB1.S31 (S2), USB1.S32 (S2), USB1.S33 (S2), USB1.S34 (S2), USB1.S35 (S2), USB1.S36 (S2), USB1.S37 (S4), USB1.S38 (S4), USB1.S39 (S4), USB1.S40 (S4), USB1.S41 (S4), USB1.S42 (S4), USB1.S43 (S4), USB1.S44 (S4), USB1.S45 (S4), USB1.S46 (S4), USB1.S47 (S4), USB1.S48 (S4), X1.P$1 (1); also elsewhere on the board
unnamed: C6.2, Q2.P$2 (2), U4.1 (PA00(XIN32/SER1:0/TC2:0))
unnamed: C4.1, R2.2
unnamed: C7.1, Q2.P$1 (1), U4.2 (PA01(XOUT32/SER1:1/TC2:1))
unnamed: RN1.1, RX.+
unnamed: RN1.2 (1), TX.+
unnamed: R5.1, R6.2, U2.4 (FB)
unnamed: D1.A, Q1.1 (G), R1.2, U2.6 (EN)
unnamed: R3.2, U2.5 (RT)
unnamed: L.+, RN1.3 (1)
unnamed: 3.3V.+, RN1.4 (1)
unnamed: C4.2, U2.3 (VC)
unnamed: C8.1, U2.7 (BST)
unnamed: C8.2, D2.2 (-), L1.P$1 (1), U2.1 (LX)
unnamed: R30.1, USB1.B5 (B5/CC2)
unnamed: R29.2, USB1.A5 (A5/CC1)
POWERSTEP_CS: TP6.1, U4.3 (PA02(AIN0/DAC)); also elsewhere on the board
POWERSTEP_MISO: TP4.1, U4.29 (PA20(SER5:2+)); also elsewhere on the board
POWERSTEP_MOSI: TP3.1, U4.25 (PA16(I2C/SER1:0+)); also elsewhere on the board
POWERSTEP_RESET: U4.8 (PB09(AIN3/SER4:1/TC4:1)); also elsewhere on the board
POWERSTEP_SCK: TP5.1, U4.28 (PA19(SER1:3+)); also elsewhere on the board
RX_LED: RX.-, U4.48 (PB03(AIN11/SER5:1))
SCL: J8.4, R35.1, U4.32 (PA23(I2C/SER3:0+))
SDA: J8.3, R36.1, U4.31 (PA22(I2C/SER3:0+))
SD_CS: J2.2 (CD/DAT3), U4.13 (PA08(I2C/AIN16/SER0:0+))
SD_DETECT: J2.CD (CARD_DETECTION), U4.10 (PA05(AIN5/SER0:1/TC0:1))
SPI_MISO: J2.7 (DAT0), U4.21 (PA12(I2C/SER2:0+)); also elsewhere on the board
SPI_MOSI: J2.3 (CMD), U4.19 (PB10(SER4:2+)); also elsewhere on the board
SPI_SCK: J2.5 (CLK), U4.20 (PB11(SER4:3+)); also elsewhere on the board
SWCLK: SWD.P$4 (SWDCLK/TCK), TP18.1, U4.45 (PA30(SWCLK/SER1:2+))
SWDIO: SWD.P$2 (SWDIO/TMS), TP17.1, U4.46 (PA31(SWDIO/SER1:3+))
TX_LED: TX.-, U4.39 (PA27)
USB_D_N: U1.3 (I/O2), U4.33 (PA24(SER3:2+))
USB_D_P: U1.1 (I/O1), U4.34 (PA25(SER3:3+))
USB_HOST_EN: U4.41 (PA28)
VDDCORE: C10.1, U4.43 (VDDCORE)
VIN: C1.1, C2.1, C3.2, D1.C, Q1.3 (S), U2.8 (VCC); also elsewhere on the board
VRAW: J1.P$2 (PWR), J1.P$3 (PWR), J1.P$4 (PWR), J1.P$5 (PWR), J1.P$6 (PWR), J1.P$7 (PWR), J1.P$8 (PWR), J1.P$9 (PWR), J1.P$10 (PWR), J1.P$11 (PWR), J1.P$12 (PWR), J1.P$13 (PWR), J1.P$14 (PWR), J1.P$15 (PWR), J1.P$16 (PWR), J1.P$17 (PWR), J1.P$18 (PWR), J1.P$19 (PWR), J1.P$20 (PWR), J1.P$21 (PWR), J1.P$22 (PWR), J1.P$23 (PWR), J1.P$24 (PWR), J1.P$25 (PWR), J1.P$26 (PWR), J1.P$27 (PWR), J1.P$28 (PWR), Q1.4 (D), X1.P$2 (2)
W5500_CS: U4.27 (PA18(SER1:2+)); also elsewhere on the board
W5500_RST: U4.9 (PA04(AIN4/REFB/SER0:0/TC0:0)); also elsewhere on the board

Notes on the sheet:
PB22/23 are TXD/RXD - they go to the EDBG
PA13 is DGI GPIO0 (goes to EDBG).
ATSAMD21G18 VDD Range: 1.62-3.63V
D30
D12 PowerSTEP SCK
D10 W5500 CS
D11 PowerSTEP MOSI
D13
D6 PowerSTEP MISO
D38
12-72V input
W5500 MISO
W5500 MOSI
W5500 SCK
SDA
SCL
D31
r1 memo
updated components - screw terminal+power jack - EM board connector - swap limit and home SW - add a shift register for dip sw
Power Symbols - GND - 5V - 3.3V - +3V3A, +3V3D - VRAW - VIN // L, BUSY, RX, TX, FLAG TP;GND;5V;3.3V;+3V3A;+3V3D;VRAW;VIN;L;BUSY;RX;TX;FLAG;

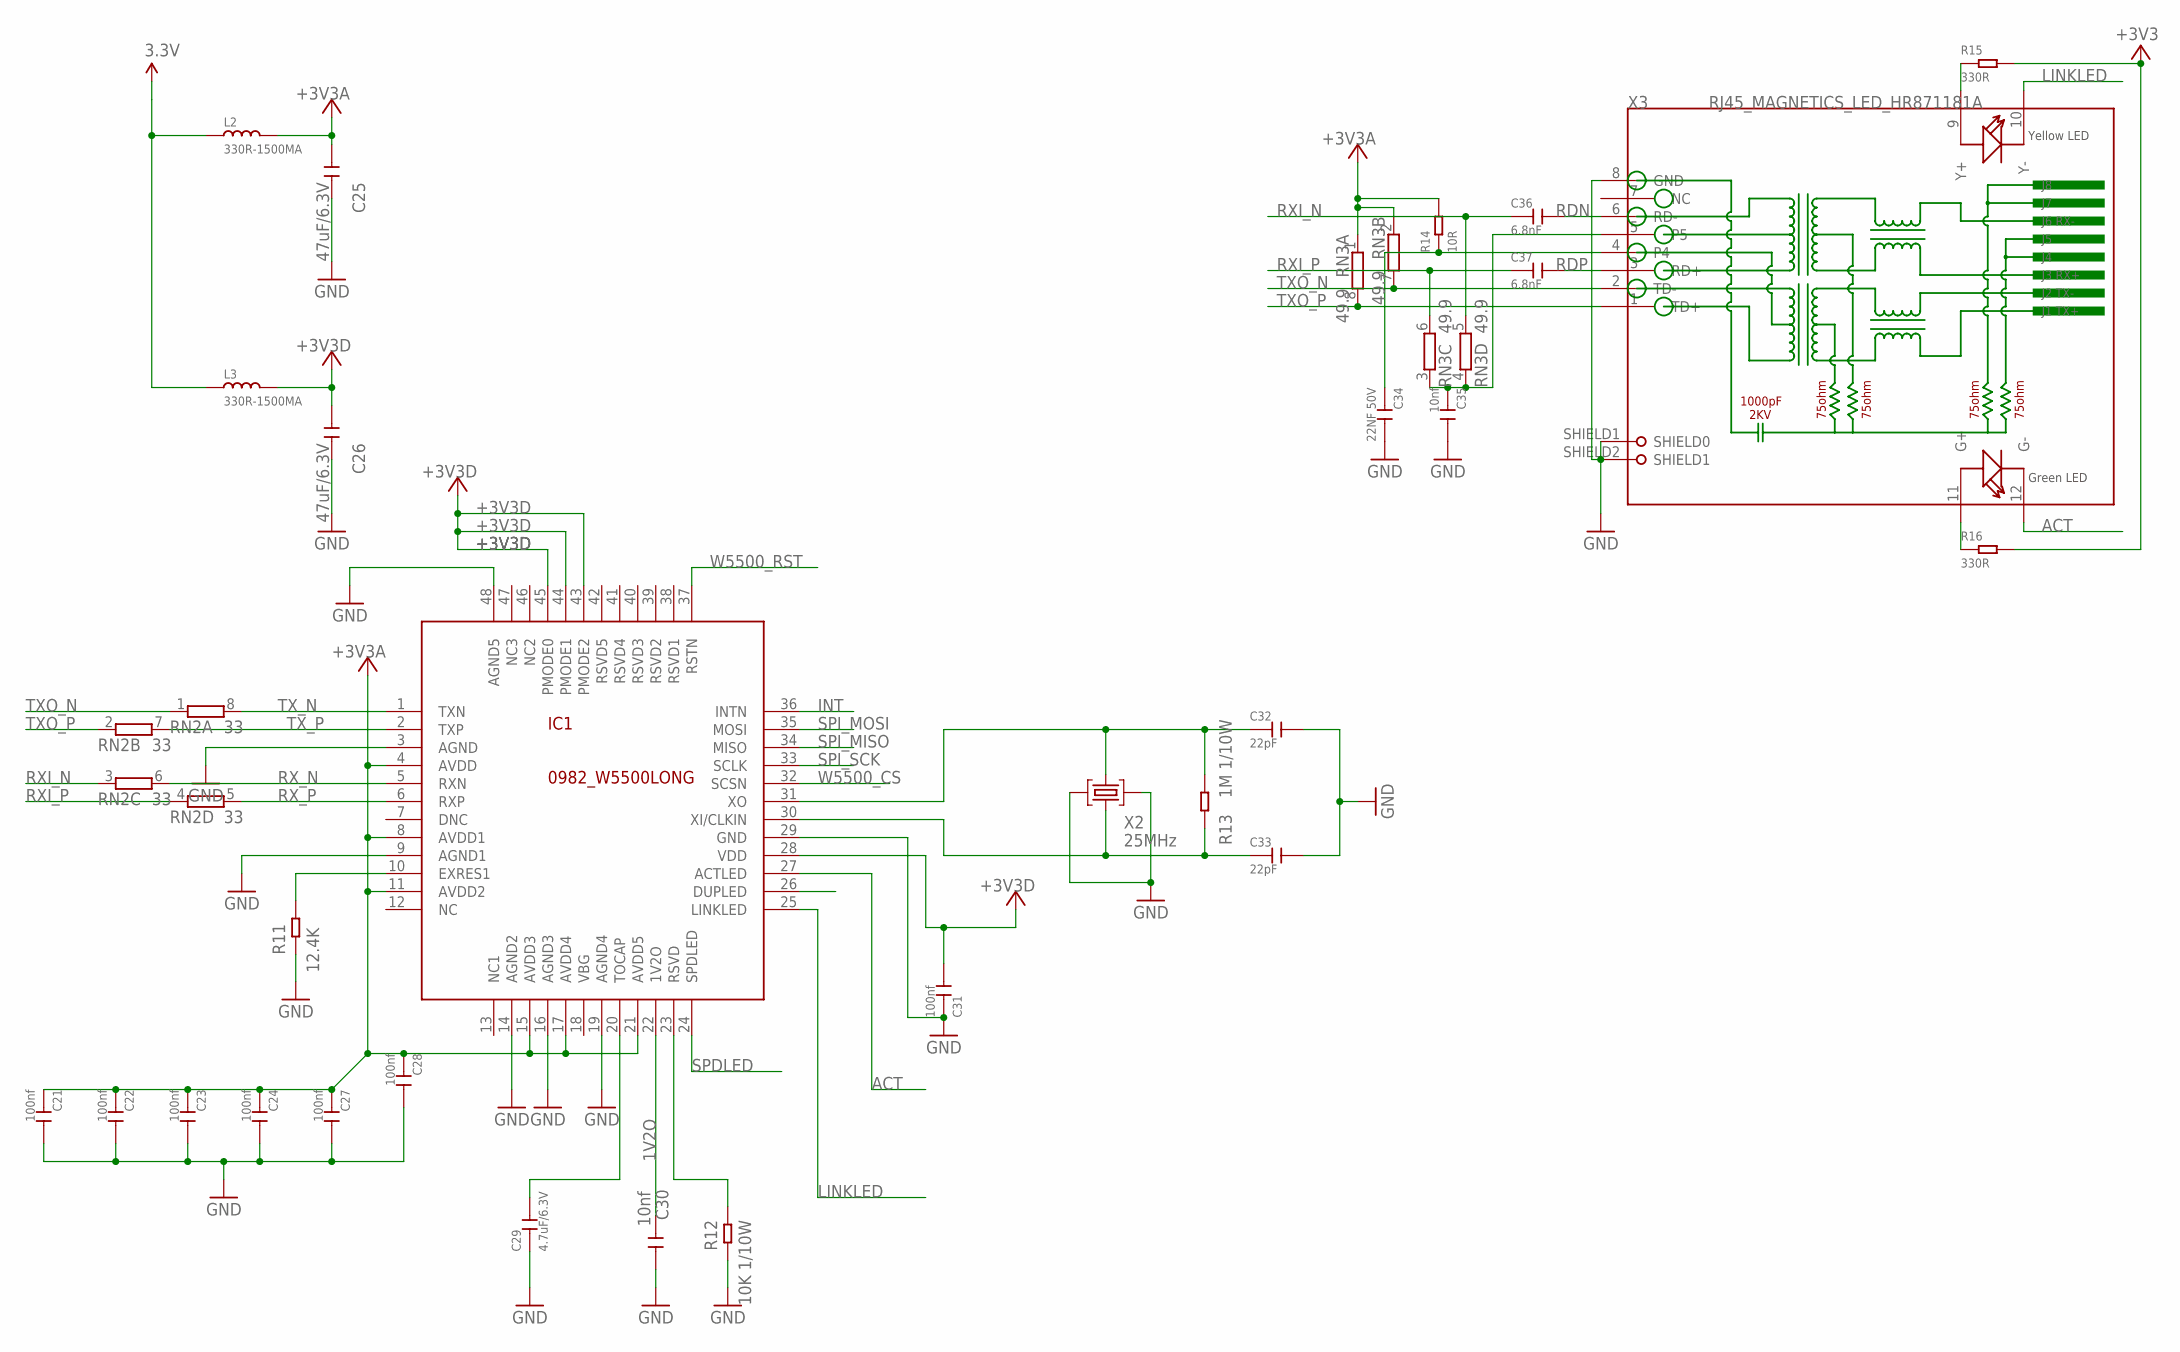
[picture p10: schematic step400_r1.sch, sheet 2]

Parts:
C21, C22, C23, C24, C27, C28, C31: 100nf; C0402
C25, C26: 47uF/6.3V; C1206
C29: 4.7uF/6.3V; C0603
C30, C35: 10nf; C0402
C32, C33: 22pF; C0402
C34: 22NF 50V; C0402
C36, C37: 6.8nF; C0402
IC1: 0982_W5500LONG; TQFP48-LONG
L2, L3: 330R-1500MA; L0805
R11: 12.4K; R0603
R12: 10K 1/10W; R0603
R13: 1M 1/10W; R0603
R14: 10R; R0603
R15, R16: 330R; R0603
RN2: 33; CAY16_LONG_W
RN3: 49.9; CAY16_LONG_W
X2: 25MHz; CRYSTAL-3.2-2.5
X3: RJ45_MAGNETICS_LED_HR871181A; HR871181A

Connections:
1V2O: C30.2, IC1.22 (1V2O)
3.3V: L2.1, L3.1, R15.2, R16.2; also elsewhere on the board
+3V3A: C21.1, C22.1, C23.1, C24.1, C25.1, C27.1, C28.1, IC1.4 (AVDD), IC1.8 (AVDD1), IC1.11 (AVDD2), IC1.15 (AVDD3), IC1.17 (AVDD4), IC1.21 (AVDD5), L2.2, R14.2, RN3.1, RN3.2 (1)
+3V3D: C26.1, C31.2, IC1.28 (VDD), IC1.43 (PMODE2), IC1.44 (PMODE1), IC1.45 (PMODE0), L3.2
ACT: IC1.27 (ACTLED), X3.12 (G-)
FDXLED: IC1.26 (DUPLED)
GND: C21.2, C22.2, C23.2, C24.2, C25.2, C26.2, C27.2, C28.2, C29.1, C30.1, C31.1, C32.2, C33.2, C34.2, C35.2, IC1.3 (AGND), IC1.9 (AGND1), IC1.14 (AGND2), IC1.16 (AGND3), IC1.19 (AGND4), IC1.29 (GND), IC1.48 (AGND5), R11.1, R12.1, X2.2 (GND), X2.4 (GND), X3.8 (GND), X3.SHIELD1 (SHIELD0), X3.SHIELD2 (SHIELD1); also elsewhere on the board
INT: IC1.36 (INTN)
LINKLED: IC1.25 (LINKLED), X3.10 (Y-)
unnamed: C32.1, IC1.31 (XO), R13.1, X2.3 (C2)
unnamed: C34.1, R14.1, X3.4
unnamed: C35.1, RN3.3 (1), RN3.4 (1), X3.5
unnamed: R15.1, X3.9 (Y+)
unnamed: R16.1, X3.11 (G+)
unnamed: IC1.23 (RSVD), R12.2
unnamed: C29.2, IC1.20 (TOCAP)
unnamed: IC1.10 (EXRES1), R11.2
NC: IC1.12 (NC)
OSC2E2: C33.1, IC1.30 (XI/CLKIN), R13.2, X2.1 (C1)
RDN: C36.2, X3.6 (RD-)
RDP: C37.2, X3.3 (RD+)
RSVD1: IC1.38 (RSVD1)
RSVD2: IC1.39 (RSVD2)
RSVD3: IC1.40 (RSVD3)
RXI_N: C36.1, RN2.3 (1), RN3.5 (2)
RXI_P: C37.1, RN2.4 (1), RN3.6 (2)
RX_N: IC1.5 (RXN), RN2.6 (2)
RX_P: IC1.6 (RXP), RN2.5 (2)
SPDLED: IC1.24 (SPDLED)
SPI_MISO: IC1.34 (MISO); also elsewhere on the board
SPI_MOSI: IC1.35 (MOSI); also elsewhere on the board
SPI_SCK: IC1.33 (SCLK); also elsewhere on the board
TXO_N: RN2.1, RN3.7 (2), X3.2 (TD-)
TXO_P: RN2.2 (1), RN3.8 (2), X3.1 (TD+)
TX_N: IC1.1 (TXN), RN2.8 (2)
TX_P: IC1.2 (TXP), RN2.7 (2)
W5500_CS: IC1.32 (SCSN); also elsewhere on the board
W5500_RST: IC1.37 (RSTN); also elsewhere on the board

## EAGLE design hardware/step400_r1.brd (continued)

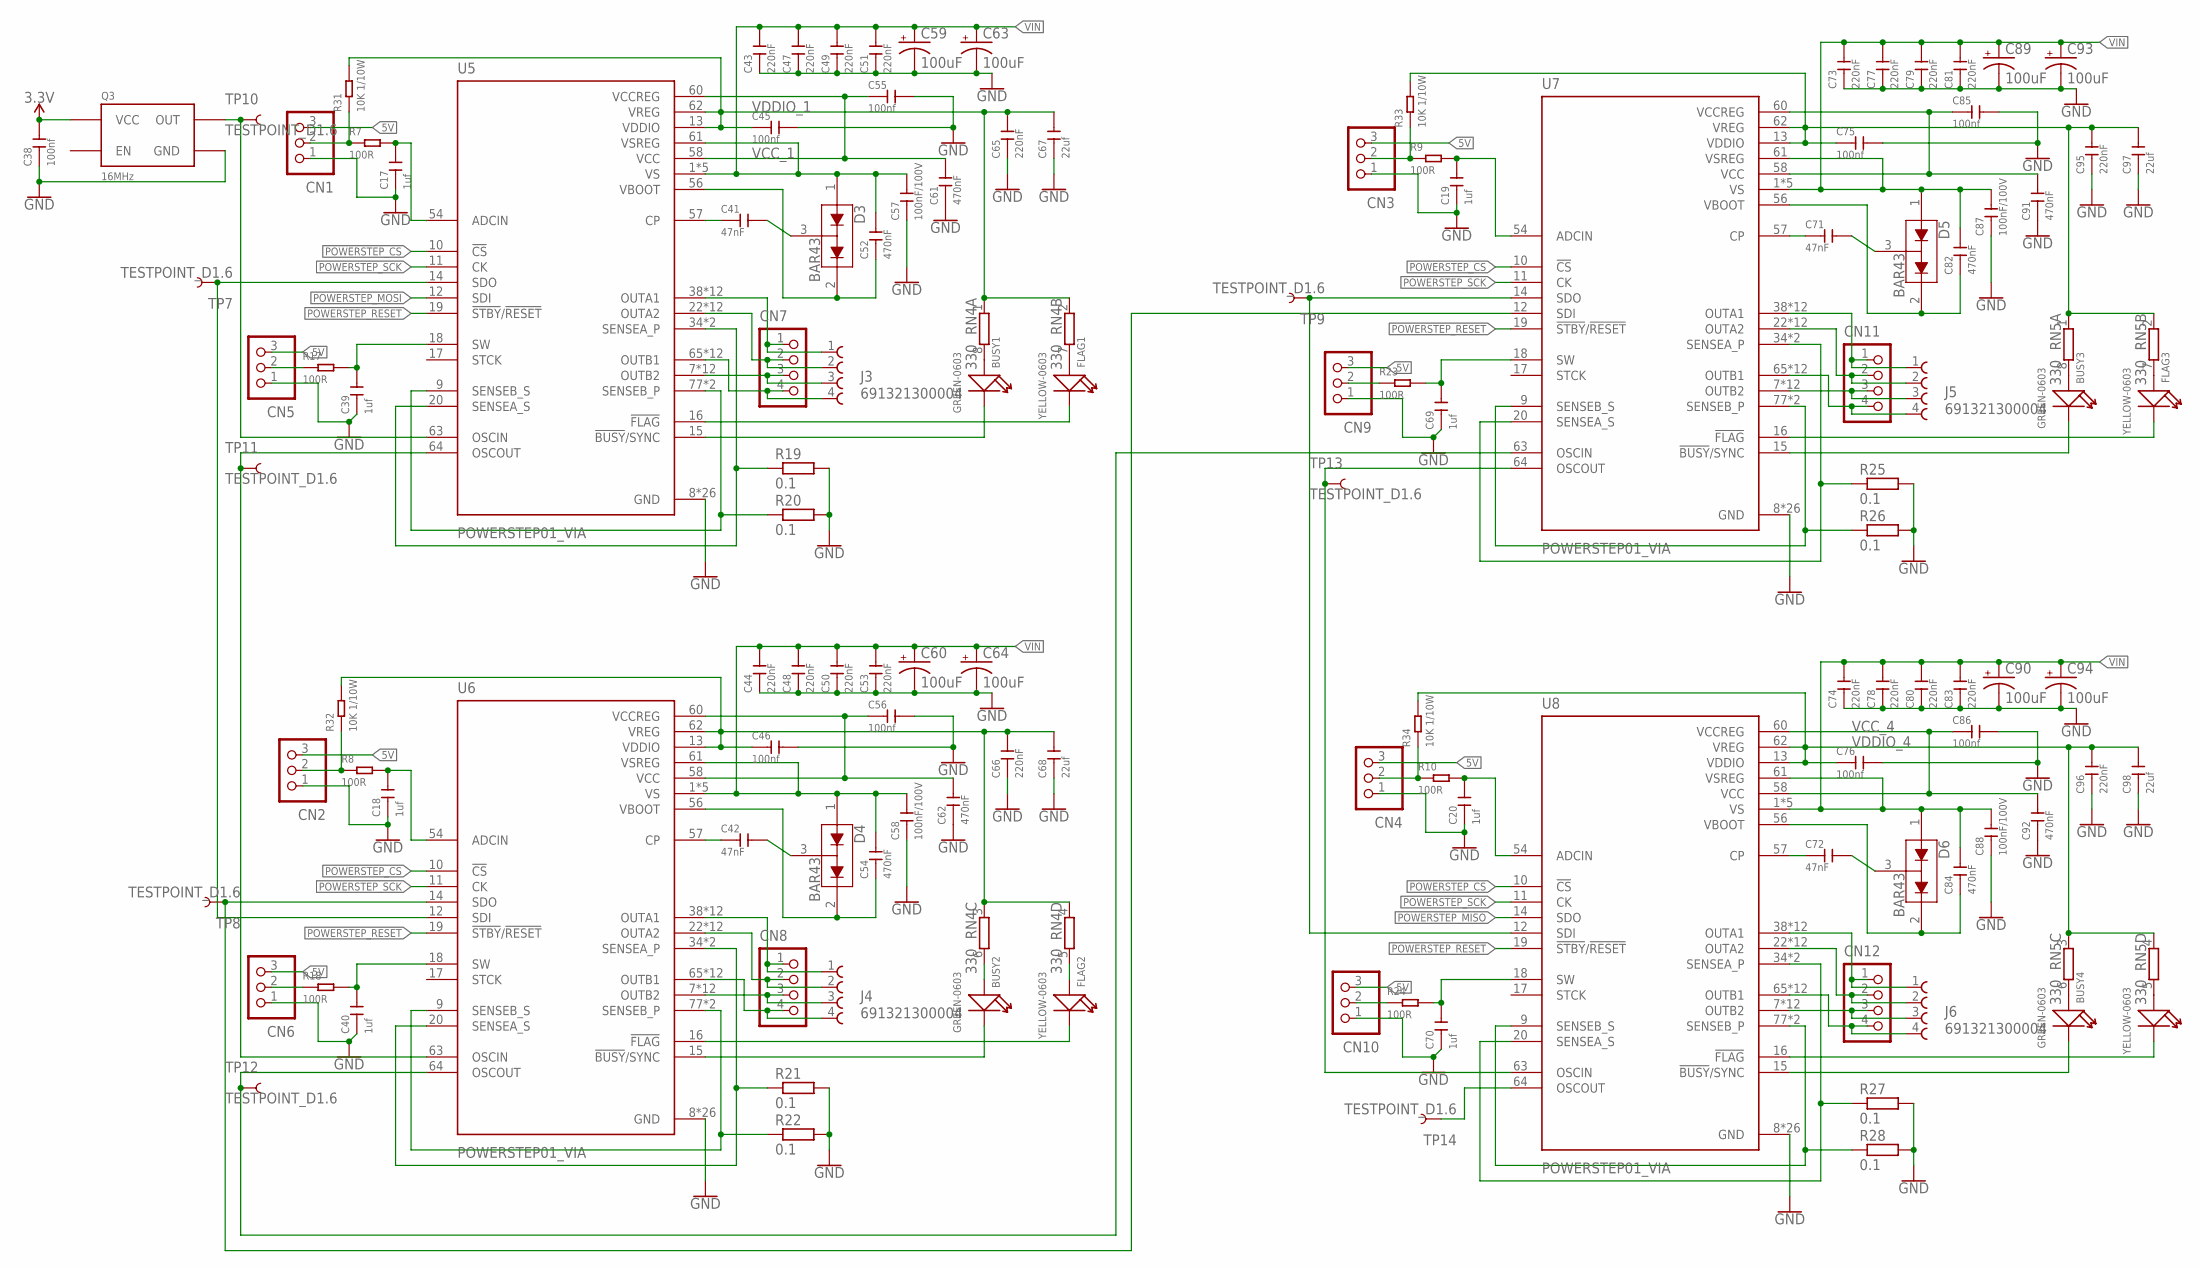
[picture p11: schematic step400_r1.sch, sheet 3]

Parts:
BUSY1, BUSY2, BUSY3, BUSY4: GREEN-0603; LED-0603
C17, C18, C19, C20, C39, C40, C69, C70: 1uf; C0603
C38, C45, C46, C55, C56, C75, C76, C85, C86: 100nf; C0402
C41, C42, C71, C72: 47nF; C0805
C43, C44, C47, C48, C49, C50, C51, C53, C73, C74, C77, C78, C79, C80, C81, C83: 220nF; C0805
C52, C54, C61, C62, C82, C84, C91, C92: 470nF; C0603
C57, C58, C87, C88: 100nF/100V; C0805
C59, C60, C63, C64, C89, C90, C93, C94: 100uF; E5-10,5
C65, C66, C95, C96: 220nF; C0402
C67, C68, C97, C98: 22uf; C0805
CN1, CN2, CN3, CN4, CN5, CN6, CN9, CN10: B3B-XASK-1
CN7, CN8, CN11, CN12: B4B-XASK-1
D3, D4, D5, D6: BAR43; SOT23-3
FLAG1, FLAG2, FLAG3, FLAG4: YELLOW-0603; LED-0603
J3, J4, J5, J6: 691321300004
Q3: 16MHz; SG5032
R7, R8, R9, R10, R17, R18, R23, R24: 100R; R0603
R19, R20, R21, R22, R25, R26, R27, R28: 0.1; RESC6332X71N
R31, R32, R33, R34: 10K 1/10W; R0603
RN4, RN5: 330; CAY16_LONG_W
TP7, TP8, TP9, TP10, TP11, TP12, TP13, TP14: TESTPOINT_D1.6
U5, U6, U7, U8: POWERSTEP01_VIA; IC_POWERSTEP01_VIA

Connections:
3.3V: C38.2, Q3.4 (VCC); also elsewhere on the board
5V: CN1.3, CN2.3, CN3.3, CN4.3, CN5.3, CN6.3, CN9.3, CN10.3; also elsewhere on the board
GND: C17.1, C18.1, C19.1, C20.1, C38.1, C39.1, C40.1, C43.1, C44.1, C45.2, C46.2, C47.1, C48.1, C49.1, C50.1, C51.1, C53.1, C55.2, C56.2, C57.1, C58.1, C59.-, C60.-, C61.1, C62.1, C63.-, C64.-, C65.1, C66.1, C67.1, C68.1, C69.1, C70.1, C73.1, C74.1, C75.2, C76.2, C77.1, C78.1, C79.1, C80.1, C81.1, C83.1, C85.2, C86.2, C87.1, C88.1, C89.-, C90.-, C91.1, C92.1, C93.-, C94.-, C95.1, C96.1, C97.1, C98.1, CN1.1, CN2.1, CN3.1, CN4.1, CN5.1, CN6.1, CN9.1, CN10.1, Q3.2 (GND), R19.2, R20.2, R21.2, R22.2, R25.2, R26.2, R27.2, R28.2, U5.8 (GND), U5.21 (GND), U5.59 (GND), U5.EPAD9 (GND), U5.EPAD9_VIA1 (GND), U5.EPAD9_VIA2 (GND), U5.EPAD9_VIA3 (GND), U5.EPAD9_VIA4 (GND), U5.EPAD9_VIA5 (GND), U5.EPAD9_VIA6 (GND), U5.EPAD9_VIA7 (GND), U5.EPAD9_VIA8 (GND), U5.EPAD9_VIA9 (GND), U5.EPAD9_VIA10 (GND), U5.EPAD9_VIA11 (GND), U5.EPAD9_VIA12 (GND), U5.EPAD9_VIA13 (GND), U5.EPAD9_VIA14 (GND), U5.EPAD9_VIA15 (GND), U5.EPAD9_VIA16 (GND), U5.EPAD9_VIA17 (GND), U5.EPAD9_VIA18 (GND), U5.EPAD9_VIA19 (GND), U5.EPAD9_VIA20 (GND), U5.EPAD9_VIA21 (GND), U5.EPAD9_VIA22 (GND), U6.8 (GND), U6.21 (GND), U6.59 (GND), U6.EPAD9 (GND), U6.EPAD9_VIA1 (GND), U6.EPAD9_VIA2 (GND), U6.EPAD9_VIA3 (GND), U6.EPAD9_VIA4 (GND), U6.EPAD9_VIA5 (GND), U6.EPAD9_VIA6 (GND), U6.EPAD9_VIA7 (GND), U6.EPAD9_VIA8 (GND), U6.EPAD9_VIA9 (GND), U6.EPAD9_VIA10 (GND), U6.EPAD9_VIA11 (GND), U6.EPAD9_VIA12 (GND), U6.EPAD9_VIA13 (GND), U6.EPAD9_VIA14 (GND), U6.EPAD9_VIA15 (GND), U6.EPAD9_VIA16 (GND), U6.EPAD9_VIA17 (GND), U6.EPAD9_VIA18 (GND), U6.EPAD9_VIA19 (GND), U6.EPAD9_VIA20 (GND), U6.EPAD9_VIA21 (GND), U6.EPAD9_VIA22 (GND), U7.8 (GND), U7.21 (GND), U7.59 (GND), U7.EPAD9 (GND), U7.EPAD9_VIA1 (GND), U7.EPAD9_VIA2 (GND), U7.EPAD9_VIA3 (GND), U7.EPAD9_VIA4 (GND), U7.EPAD9_VIA5 (GND), U7.EPAD9_VIA6 (GND), U7.EPAD9_VIA7 (GND), U7.EPAD9_VIA8 (GND), U7.EPAD9_VIA9 (GND), U7.EPAD9_VIA10 (GND), U7.EPAD9_VIA11 (GND), U7.EPAD9_VIA12 (GND), U7.EPAD9_VIA13 (GND), U7.EPAD9_VIA14 (GND), U7.EPAD9_VIA15 (GND), U7.EPAD9_VIA16 (GND), U7.EPAD9_VIA17 (GND), U7.EPAD9_VIA18 (GND), U7.EPAD9_VIA19 (GND), U7.EPAD9_VIA20 (GND), U7.EPAD9_VIA21 (GND), U7.EPAD9_VIA22 (GND), U8.8 (GND), U8.21 (GND), U8.59 (GND), U8.EPAD9 (GND), U8.EPAD9_VIA1 (GND), U8.EPAD9_VIA2 (GND), U8.EPAD9_VIA3 (GND), U8.EPAD9_VIA4 (GND), U8.EPAD9_VIA5 (GND), U8.EPAD9_VIA6 (GND), U8.EPAD9_VIA7 (GND), U8.EPAD9_VIA8 (GND), U8.EPAD9_VIA9 (GND), U8.EPAD9_VIA10 (GND), U8.EPAD9_VIA11 (GND), U8.EPAD9_VIA12 (GND), U8.EPAD9_VIA13 (GND), U8.EPAD9_VIA14 (GND), U8.EPAD9_VIA15 (GND), U8.EPAD9_VIA16 (GND), U8.EPAD9_VIA17 (GND), U8.EPAD9_VIA18 (GND), U8.EPAD9_VIA19 (GND), U8.EPAD9_VIA20 (GND), U8.EPAD9_VIA21 (GND), U8.EPAD9_VIA22 (GND); also elsewhere on the board
LIMIT1: C17.2, R7.2, U5.54 (ADCIN)
LIMIT2: C18.2, R8.2, U6.54 (ADCIN)
LIMIT3: C19.2, R9.2, U7.54 (ADCIN)
LIMIT4: C20.2, R10.2, U8.54 (ADCIN)
unnamed: TP14.1, U8.64 (OSCOUT)
unnamed: CN1.2, R7.1, R31.1
unnamed: CN2.2, R8.1, R32.1
unnamed: BUSY1.+, RN4.8 (2)
unnamed: CN5.2, R17.1
unnamed: C39.2, R17.2, U5.18 (SW)
unnamed: C40.2, R18.2, U6.18 (SW)
unnamed: CN6.2, R18.1
unnamed: C69.2, R23.2, U7.18 (SW)
unnamed: CN9.2, R23.1
unnamed: FLAG1.+, RN4.7 (2)
unnamed: C70.2, R24.2, U8.18 (SW)
unnamed: C41.2, D3.3 (COM)
unnamed: C41.1, U5.57 (CP)
unnamed: CN10.2, R24.1
unnamed: CN3.2, R9.1, R33.1
unnamed: BUSY2.+, RN4.6 (2)
unnamed: FLAG2.+, RN4.5 (2)
unnamed: FLAG1.-, U5.16 (!FLAG)
unnamed: BUSY1.-, U5.15 (!BUSY!/SYNC)
unnamed: R20.1, U5.9 (SENSEB_S), U5.77 (SENSEB_P), U5.82 (SENSEB_P)
unnamed: R19.1, U5.20 (SENSEA_S), U5.34 (SENSEA_P), U5.39 (SENSEA_P)
unnamed: CN4.2, R10.1, R34.1
unnamed: CN7.1, J3.1, U5.38 (OUTA1), U5.42 (OUTA1), U5.53 (OUTA1), U5.EPAD4 (OUTA1), U5.EPAD4_VIA1 (OUTA1), U5.EPAD4_VIA2 (OUTA1), U5.EPAD4_VIA3 (OUTA1), U5.EPAD4_VIA4 (OUTA1), U5.EPAD4_VIA5 (OUTA1), U5.EPAD4_VIA6 (OUTA1), U5.EPAD4_VIA7 (OUTA1), U5.EPAD4_VIA8 (OUTA1)
unnamed: CN7.2, J3.2, U5.22 (OUTA2), U5.33 (OUTA2), U5.37 (OUTA2), U5.EPAD3 (OUTA2), U5.EPAD3_VIA1 (OUTA2), U5.EPAD3_VIA2 (OUTA2), U5.EPAD3_VIA3 (OUTA2), U5.EPAD3_VIA4 (OUTA2), U5.EPAD3_VIA5 (OUTA2), U5.EPAD3_VIA6 (OUTA2), U5.EPAD3_VIA7 (OUTA2), U5.EPAD3_VIA8 (OUTA2)
unnamed: TP7.1, U5.14 (SDO), U6.12 (SDI)
unnamed: CN7.3, J3.3, U5.7 (OUTB2), U5.81 (OUTB2), U5.85 (OUTB2), U5.EPAD8 (OUTB2), U5.EPAD8_VIA1 (OUTB2), U5.EPAD8_VIA2 (OUTB2), U5.EPAD8_VIA3 (OUTB2), U5.EPAD8_VIA4 (OUTB2), U5.EPAD8_VIA5 (OUTB2), U5.EPAD8_VIA6 (OUTB2), U5.EPAD8_VIA7 (OUTB2), U5.EPAD8_VIA8 (OUTB2)
unnamed: CN7.4, J3.4, U5.65 (OUTB1), U5.76 (OUTB1), U5.80 (OUTB1), U5.EPAD7 (OUTB1), U5.EPAD7_VIA1 (OUTB1), U5.EPAD7_VIA2 (OUTB1), U5.EPAD7_VIA3 (OUTB1), U5.EPAD7_VIA4 (OUTB1), U5.EPAD7_VIA5 (OUTB1), U5.EPAD7_VIA6 (OUTB1), U5.EPAD7_VIA7 (OUTB1), U5.EPAD7_VIA8 (OUTB1)
unnamed: C42.2, D4.3 (COM)
unnamed: C42.1, U6.57 (CP)
unnamed: BUSY3.+, RN5.8 (2)
unnamed: FLAG3.+, RN5.7 (2)
unnamed: FLAG2.-, U6.16 (!FLAG)
unnamed: BUSY2.-, U6.15 (!BUSY!/SYNC)
unnamed: R22.1, U6.9 (SENSEB_S), U6.77 (SENSEB_P), U6.82 (SENSEB_P)
unnamed: R21.1, U6.20 (SENSEA_S), U6.34 (SENSEA_P), U6.39 (SENSEA_P)
unnamed: TP12.1, U6.64 (OSCOUT), U7.63 (OSCIN)
unnamed: CN8.1, J4.1, U6.38 (OUTA1), U6.42 (OUTA1), U6.53 (OUTA1), U6.EPAD4 (OUTA1), U6.EPAD4_VIA1 (OUTA1), U6.EPAD4_VIA2 (OUTA1), U6.EPAD4_VIA3 (OUTA1), U6.EPAD4_VIA4 (OUTA1), U6.EPAD4_VIA5 (OUTA1), U6.EPAD4_VIA6 (OUTA1), U6.EPAD4_VIA7 (OUTA1), U6.EPAD4_VIA8 (OUTA1)
unnamed: CN8.2, J4.2, U6.22 (OUTA2), U6.33 (OUTA2), U6.37 (OUTA2), U6.EPAD3 (OUTA2), U6.EPAD3_VIA1 (OUTA2), U6.EPAD3_VIA2 (OUTA2), U6.EPAD3_VIA3 (OUTA2), U6.EPAD3_VIA4 (OUTA2), U6.EPAD3_VIA5 (OUTA2), U6.EPAD3_VIA6 (OUTA2), U6.EPAD3_VIA7 (OUTA2), U6.EPAD3_VIA8 (OUTA2)
unnamed: CN8.3, J4.3, U6.7 (OUTB2), U6.81 (OUTB2), U6.85 (OUTB2), U6.EPAD8 (OUTB2), U6.EPAD8_VIA1 (OUTB2), U6.EPAD8_VIA2 (OUTB2), U6.EPAD8_VIA3 (OUTB2), U6.EPAD8_VIA4 (OUTB2), U6.EPAD8_VIA5 (OUTB2), U6.EPAD8_VIA6 (OUTB2), U6.EPAD8_VIA7 (OUTB2), U6.EPAD8_VIA8 (OUTB2)
unnamed: CN8.4, J4.4, U6.65 (OUTB1), U6.76 (OUTB1), U6.80 (OUTB1), U6.EPAD7 (OUTB1), U6.EPAD7_VIA1 (OUTB1), U6.EPAD7_VIA2 (OUTB1), U6.EPAD7_VIA3 (OUTB1), U6.EPAD7_VIA4 (OUTB1), U6.EPAD7_VIA5 (OUTB1), U6.EPAD7_VIA6 (OUTB1), U6.EPAD7_VIA7 (OUTB1), U6.EPAD7_VIA8 (OUTB1)
unnamed: BUSY4.+, RN5.6 (2)
unnamed: C82.1, D5.2 (C2), U7.56 (VBOOT)
unnamed: C71.2, D5.3 (COM)
unnamed: C71.1, U7.57 (CP)
unnamed: FLAG4.+, RN5.5 (2)
unnamed: CN11.4, J5.4, U7.65 (OUTB1), U7.76 (OUTB1), U7.80 (OUTB1), U7.EPAD7 (OUTB1), U7.EPAD7_VIA1 (OUTB1), U7.EPAD7_VIA2 (OUTB1), U7.EPAD7_VIA3 (OUTB1), U7.EPAD7_VIA4 (OUTB1), U7.EPAD7_VIA5 (OUTB1), U7.EPAD7_VIA6 (OUTB1), U7.EPAD7_VIA7 (OUTB1), U7.EPAD7_VIA8 (OUTB1)
unnamed: FLAG3.-, U7.16 (!FLAG)
unnamed: BUSY3.-, U7.15 (!BUSY!/SYNC)
unnamed: R26.1, U7.9 (SENSEB_S), U7.77 (SENSEB_P), U7.82 (SENSEB_P)
unnamed: R25.1, U7.20 (SENSEA_S), U7.34 (SENSEA_P), U7.39 (SENSEA_P)
unnamed: TP8.1, U6.14 (SDO), U7.12 (SDI)
unnamed: CN11.1, J5.1, U7.38 (OUTA1), U7.42 (OUTA1), U7.53 (OUTA1), U7.EPAD4 (OUTA1), U7.EPAD4_VIA1 (OUTA1), U7.EPAD4_VIA2 (OUTA1), U7.EPAD4_VIA3 (OUTA1), U7.EPAD4_VIA4 (OUTA1), U7.EPAD4_VIA5 (OUTA1), U7.EPAD4_VIA6 (OUTA1), U7.EPAD4_VIA7 (OUTA1), U7.EPAD4_VIA8 (OUTA1)
unnamed: CN11.2, J5.2, U7.22 (OUTA2), U7.33 (OUTA2), U7.37 (OUTA2), U7.EPAD3 (OUTA2), U7.EPAD3_VIA1 (OUTA2), U7.EPAD3_VIA2 (OUTA2), U7.EPAD3_VIA3 (OUTA2), U7.EPAD3_VIA4 (OUTA2), U7.EPAD3_VIA5 (OUTA2), U7.EPAD3_VIA6 (OUTA2), U7.EPAD3_VIA7 (OUTA2), U7.EPAD3_VIA8 (OUTA2)
unnamed: CN11.3, J5.3, U7.7 (OUTB2), U7.81 (OUTB2), U7.85 (OUTB2), U7.EPAD8 (OUTB2), U7.EPAD8_VIA1 (OUTB2), U7.EPAD8_VIA2 (OUTB2), U7.EPAD8_VIA3 (OUTB2), U7.EPAD8_VIA4 (OUTB2), U7.EPAD8_VIA5 (OUTB2), U7.EPAD8_VIA6 (OUTB2), U7.EPAD8_VIA7 (OUTB2), U7.EPAD8_VIA8 (OUTB2)
unnamed: CN12.4, J6.4, U8.65 (OUTB1), U8.76 (OUTB1), U8.80 (OUTB1), U8.EPAD7 (OUTB1), U8.EPAD7_VIA1 (OUTB1), U8.EPAD7_VIA2 (OUTB1), U8.EPAD7_VIA3 (OUTB1), U8.EPAD7_VIA4 (OUTB1), U8.EPAD7_VIA5 (OUTB1), U8.EPAD7_VIA6 (OUTB1), U8.EPAD7_VIA7 (OUTB1), U8.EPAD7_VIA8 (OUTB1)
unnamed: CN12.3, J6.3, U8.7 (OUTB2), U8.81 (OUTB2), U8.85 (OUTB2), U8.EPAD8 (OUTB2), U8.EPAD8_VIA1 (OUTB2), U8.EPAD8_VIA2 (OUTB2), U8.EPAD8_VIA3 (OUTB2), U8.EPAD8_VIA4 (OUTB2), U8.EPAD8_VIA5 (OUTB2), U8.EPAD8_VIA6 (OUTB2), U8.EPAD8_VIA7 (OUTB2), U8.EPAD8_VIA8 (OUTB2)
unnamed: C84.1, D6.2 (C2), U8.56 (VBOOT)
unnamed: C72.2, D6.3 (COM)
unnamed: C72.1, U8.57 (CP)
unnamed: FLAG4.-, U8.16 (!FLAG)
unnamed: BUSY4.-, U8.15 (!BUSY!/SYNC)
unnamed: R28.1, U8.9 (SENSEB_S), U8.77 (SENSEB_P), U8.82 (SENSEB_P)
unnamed: R27.1, U8.20 (SENSEA_S), U8.34 (SENSEA_P), U8.39 (SENSEA_P)
unnamed: CN12.1, J6.1, U8.38 (OUTA1), U8.42 (OUTA1), U8.53 (OUTA1), U8.EPAD4 (OUTA1), U8.EPAD4_VIA1 (OUTA1), U8.EPAD4_VIA2 (OUTA1), U8.EPAD4_VIA3 (OUTA1), U8.EPAD4_VIA4 (OUTA1), U8.EPAD4_VIA5 (OUTA1), U8.EPAD4_VIA6 (OUTA1), U8.EPAD4_VIA7 (OUTA1), U8.EPAD4_VIA8 (OUTA1)
unnamed: CN12.2, J6.2, U8.22 (OUTA2), U8.33 (OUTA2), U8.37 (OUTA2), U8.EPAD3 (OUTA2), U8.EPAD3_VIA1 (OUTA2), U8.EPAD3_VIA2 (OUTA2), U8.EPAD3_VIA3 (OUTA2), U8.EPAD3_VIA4 (OUTA2), U8.EPAD3_VIA5 (OUTA2), U8.EPAD3_VIA6 (OUTA2), U8.EPAD3_VIA7 (OUTA2), U8.EPAD3_VIA8 (OUTA2)
unnamed: Q3.3 (OUT), TP10.1, U5.63 (OSCIN)
unnamed: TP11.1, U5.64 (OSCOUT), U6.63 (OSCIN)
unnamed: TP13.1, U7.64 (OSCOUT), U8.63 (OSCIN)
unnamed: TP9.1, U7.14 (SDO), U8.12 (SDI)
POWERSTEP_CS: U5.10 (!CS), U6.10 (!CS), U7.10 (!CS), U8.10 (!CS); also elsewhere on the board
POWERSTEP_MISO: U8.14 (SDO); also elsewhere on the board
POWERSTEP_MOSI: U5.12 (SDI); also elsewhere on the board
POWERSTEP_RESET: U5.19 (!STBY!/!RESET), U6.19 (!STBY!/!RESET), U7.19 (!STBY!/!RESET), U8.19 (!STBY!/!RESET); also elsewhere on the board
POWERSTEP_SCK: U5.11 (CK), U6.11 (CK), U7.11 (CK), U8.11 (CK); also elsewhere on the board
VBOOT_1: C52.1, D3.2 (C2), U5.56 (VBOOT)
VBOOT_2: C54.1, D4.2 (C2), U6.56 (VBOOT)
VCC_1: C55.1, C61.2, U5.58 (VCC), U5.60 (VCCREG)
VCC_2: C56.1, C62.2, U6.58 (VCC), U6.60 (VCCREG)
VCC_3: C85.1, C91.2, U7.58 (VCC), U7.60 (VCCREG)
VCC_4: C86.1, C92.2, U8.58 (VCC), U8.60 (VCCREG)
VDDIO_1: C45.1, C65.2, C67.2, R31.2, RN4.1, RN4.2 (1), U5.13 (VDDIO), U5.62 (VREG)
VDDIO_2: C46.1, C66.2, C68.2, R32.2, RN4.3 (1), RN4.4 (1), U6.13 (VDDIO), U6.62 (VREG)
VDDIO_3: C75.1, C95.2, C97.2, R33.2, RN5.1, RN5.2 (1), U7.13 (VDDIO), U7.62 (VREG)
VDDIO_4: C76.1, C96.2, C98.2, R34.2, RN5.3 (1), RN5.4 (1), U8.13 (VDDIO), U8.62 (VREG)
VIN: C43.2, C44.2, C47.2, C48.2, C49.2, C50.2, C51.2, C52.2, C53.2, C54.2, C57.2, C58.2, C59.+, C60.+, C63.+, C64.+, C73.2, C74.2, C77.2, C78.2, C79.2, C80.2, C81.2, C82.2, C83.2, C84.2, C87.2, C88.2, C89.+, C90.+, C93.+, C94.+, D3.1 (A1), D4.1 (A1), D5.1 (A1), D6.1 (A1), U5.1 (VS), U5.23 (VS), U5.43 (VS), U5.55 (VS), U5.61 (VSREG), U5.66 (VS), U6.1 (VS), U6.23 (VS), U6.43 (VS), U6.55 (VS), U6.61 (VSREG), U6.66 (VS), U7.1 (VS), U7.23 (VS), U7.43 (VS), U7.55 (VS), U7.61 (VSREG), U7.66 (VS), U8.1 (VS), U8.23 (VS), U8.43 (VS), U8.55 (VS), U8.61 (VSREG), U8.66 (VS); also elsewhere on the board

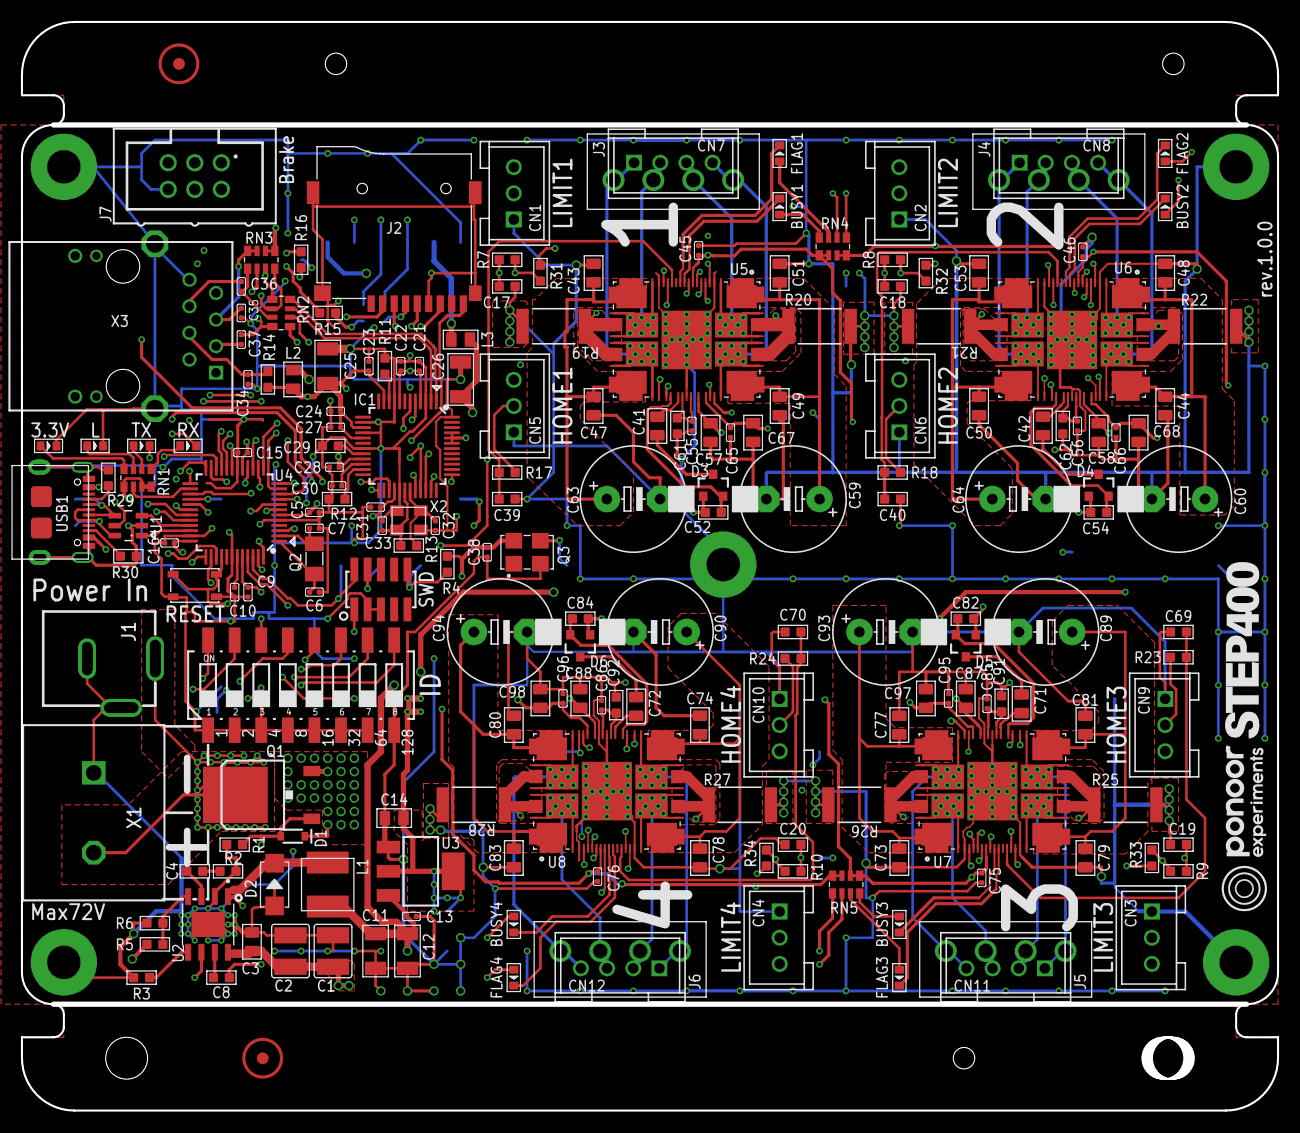
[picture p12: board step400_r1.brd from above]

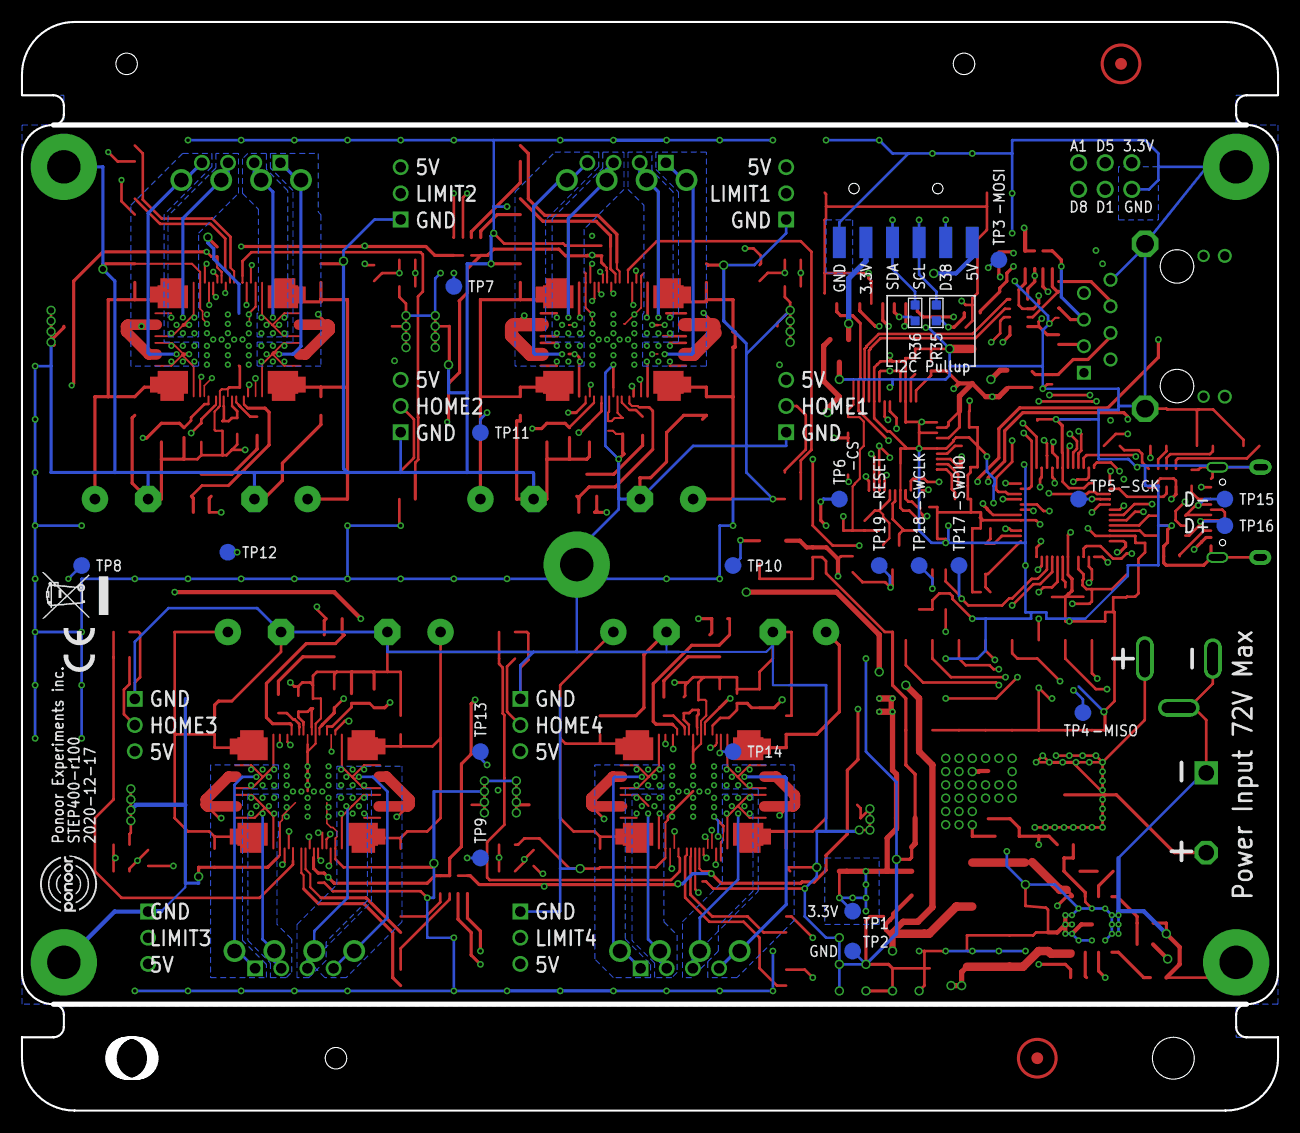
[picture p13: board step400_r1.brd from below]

Board: 4 copper layers, 120.0 x 104.0 mm, 229 parts (25 on the bottom side), 166 nets.

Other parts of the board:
U$1: STEP400_LOGO_6MM
U$2, U$3: FIDUCIAL_MARKER_PBAN
U$4: PONOOR_LOGO_6MM
U$6: WEEE_6MM
U$8: CE_3MM

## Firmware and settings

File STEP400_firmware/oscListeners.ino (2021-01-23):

void OSCMsgReceive() {
    bool bMsgHasError = false, bMsgRouted = false;
    OSCMessage msgIN;
    int size;
    if ((size = Udp.parsePacket()) > 0) {
        while (size--)
            msgIN.fill(Udp.read());

        bMsgHasError = msgIN.hasError();
        if (!bMsgHasError) {
            // some possible frequent messeages
            bMsgRouted |= msgIN.route("/setTargetPosition", setTargetPosition);
            bMsgRouted |= msgIN.route("/setTargetPositionList", setTargetPositionList);
            bMsgRouted |= msgIN.route("/getPosition", getPosition);
            bMsgRouted |= msgIN.route("/getSpeed", getSpeed);
            bMsgRouted |= msgIN.route("/run", run);
            bMsgRouted |= msgIN.route("/runRaw", runRaw);

            // motion
            bMsgRouted |= msgIN.route("/move", move);
            bMsgRouted |= msgIN.route("/goTo", goTo);
            bMsgRouted |= msgIN.route("/goToDir", goToDir);
            bMsgRouted |= msgIN.route("/goUntil", goUntil);
            bMsgRouted |= msgIN.route("/goUntilRaw", goUntilRaw);
            bMsgRouted |= msgIN.route("/releaseSw", releaseSw);
            bMsgRouted |= msgIN.route("/goHome", goHome);
            bMsgRouted |= msgIN.route("/goMark", goMark);
            bMsgRouted |= msgIN.route("/setMark", setMark);
            bMsgRouted |= msgIN.route("/getMark", getMark);
            bMsgRouted |= msgIN.route("/setPosition", setPosition);
            bMsgRouted |= msgIN.route("/resetPos", resetPos);
            bMsgRouted |= msgIN.route("/resetDev", resetDev);
            bMsgRouted |= msgIN.route("/softStop", softStop);
            bMsgRouted |= msgIN.route("/hardStop", hardStop);
            bMsgRouted |= msgIN.route("/softHiZ", softHiZ);
            bMsgRouted |= msgIN.route("/hardHiZ", hardHiZ);

            // servo mode
            bMsgRouted |= msgIN.route("/enableServoMode", enableServoMode);
            bMsgRouted |= msgIN.route("/setServoParam", setServoParam);
            bMsgRouted |= msgIN.route("/getServoParam", getServoParam);

            // speed
            bMsgRouted |= msgIN.route("/setSpeedProfile", setSpeedProfile);
            bMsgRouted |= msgIN.route("/setMaxSpeed", setMaxSpeed);
            bMsgRouted |= msgIN.route("/setFullstepSpeed", setFullstepSpeed);
            bMsgRouted |= msgIN.route("/getFullstepSpeed", getFullstepSpeed);
            bMsgRouted |= msgIN.route("/setAcc", setAcc);
            bMsgRouted |= msgIN.route("/setDec", setDec);
            bMsgRouted |= msgIN.route("/getSpeedProfile", getSpeedProfile);

            // Kval
            bMsgRouted |= msgIN.route("/setKval", setKval);
            bMsgRouted |= msgIN.route("/setAccKval", setAccKval);
            bMsgRouted |= msgIN.route("/setDecKval", setDecKval);
            bMsgRouted |= msgIN.route("/setRunKval", setRunKval);
            bMsgRouted |= msgIN.route("/setHoldKval", setHoldKval);
            bMsgRouted |= msgIN.route("/getKval", getKval);

            //TVAL
            bMsgRouted |= msgIN.route("/setTval", setTval);
            bMsgRouted |= msgIN.route("/setAccTval", setAccTval);
            bMsgRouted |= msgIN.route("/setDecTval", setDecTval);
            bMsgRouted |= msgIN.route("/setRunTval", setRunTval);
            bMsgRouted |= msgIN.route("/setHoldTval", setHoldTval);
            bMsgRouted |= msgIN.route("/getTval", getTval);
            bMsgRouted |= msgIN.route("/getTval_mA", getTval_mA);

            // config
            bMsgRouted |= msgIN.route("/setDestIp", setDestIp);
            bMsgRouted |= msgIN.route("/getVersion", getVersion);
            bMsgRouted |= msgIN.route("/getConfigName", getConfigName);
            bMsgRouted |= msgIN.route("/getConfigRegister", getConfigRegister);
            bMsgRouted |= msgIN.route("/getStatus", getStatus);
            bMsgRouted |= msgIN.route("/getStatusList", getStatusList);
            bMsgRouted |= msgIN.route("/getHomeSw", getHomeSw);
            bMsgRouted |= msgIN.route("/getBusy", getBusy);
            bMsgRouted |= msgIN.route("/getUvlo", getUvlo);
            bMsgRouted |= msgIN.route("/getMotorStatus", getMotorStatus);
            bMsgRouted |= msgIN.route("/getThermalStatus", getThermalStatus);
            bMsgRouted |= msgIN.route("/resetMotorDriver", resetMotorDriver);
            //bMsgRouted |= msgIN.route("/enableFlagReport", enableFlagReport);
            bMsgRouted |= msgIN.route("/enableBusyReport", enableBusyReport);
            bMsgRouted |= msgIN.route("/enableHizReport", enableHizReport);
            bMsgRouted |= msgIN.route("/enableHomeSwReport", enableHomeSwReport);
            bMsgRouted |= msgIN.route("/enableDirReport", enableDirReport);
            bMsgRouted |= msgIN.route("/enableMotorStatusReport", enableMotorStatusReport);
            bMsgRouted |= msgIN.route("/enableSwEventReport", enableSwEventReport);
            bMsgRouted |= msgIN.route("/enableCommandErrorReport", enableCommandErrorReport);
            bMsgRouted |= msgIN.route("/enableUvloReport", enableUvloReport);
            bMsgRouted |= msgIN.route("/enableThermalStatusReport", enableThermalStatusReport);
            bMsgRouted |= msgIN.route("/enableOverCurrentReport", enableOverCurrentReport);
            bMsgRouted |= msgIN.route("/enableStallReport", enableStallReport);
            //bMsgRouted |= msgIN.route("/getDir", getDir);
            bMsgRouted |= msgIN.route("/getLimitSw", getLimitSw);
            bMsgRouted |= msgIN.route("/getLimitSwMode", getLimitSwMode);
            bMsgRouted |= msgIN.route("/setLimitSwMode", setLimitSwMode);
            bMsgRouted |= msgIN.route("/enableLimitSwReport", enableLimitSwReport);

            bMsgRouted |= msgIN.route("/setMicrostepMode", setMicrostepMode);
            bMsgRouted |= msgIN.route("/getMicrostepMode", getMicrostepMode);
            bMsgRouted |= msgIN.route("/getHomeSwMode", getHomeSwMode);
            bMsgRouted |= msgIN.route("/setHomeSwMode", setHomeSwMode);
            bMsgRouted |= msgIN.route("/setStallThreshold", setStallThreshold);
            bMsgRouted |= msgIN.route("/getStallThreshold", getStallThreshold);
            bMsgRouted |= msgIN.route("/setOverCurrentThreshold", setOverCurrentThreshold);
            bMsgRouted |= msgIN.route("/getOverCurrentThreshold", getOverCurrentThreshold);
            bMsgRouted |= msgIN.route("/setLowSpeedOptimizeThreshold", setLowSpeedOptimizeThreshold);
            bMsgRouted |= msgIN.route("/getLowSpeedOptimizeThreshold", getLowSpeedOptimizeThreshold);
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

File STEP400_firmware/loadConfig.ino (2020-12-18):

void loadConfig() {
    uint8_t i;
    if (digitalRead(SD_DETECT_PIN) == LOW)
    {
        sdInitializeSucceeded = SD.begin(SD_CS_PIN);
    }

    File file = SD.open(filename);
    configFileOpenSucceeded = (file != false);
    // Allocate a temporary JsonDocument
    // Don't forget to change the capacity to match your requirements.
    // Use arduinojson.org/v6/assistant to compute the capacity.
    const size_t capacity = 49 * JSON_ARRAY_SIZE(4) + JSON_ARRAY_SIZE(6) + JSON_OBJECT_SIZE(1) + JSON_OBJECT_SIZE(3) + JSON_OBJECT_SIZE(4) + JSON_OBJECT_SIZE(6) + JSON_OBJECT_SIZE(7) + JSON_OBJECT_SIZE(8) + JSON_OBJECT_SIZE(10) + JSON_OBJECT_SIZE(13) + JSON_OBJECT_SIZE(14) + 830;
    DynamicJsonDocument doc(capacity);
    DeserializationError error = deserializeJson(doc, file);
    configFileParseSucceeded = (error == false);
    file.close();
    SD.end();

    // Information
    configName = doc["information"]["configName"] | "Default";

    // Network
    JsonObject network = doc["network"];
    JsonArray network_myIp = network["myIp"];
    JsonArray network_destIp = network["destIp"];
    JsonArray network_dns = network["dns"];
    JsonArray network_gateway = network["gateway"];
    JsonArray network_subnet = network["subnet"];
    for (i = 0; i < 4; i++) {
        myIp[i] = network_myIp[i] | myIp[i];
        destIp[i] = network_destIp[i] | destIp[i];
        dns[i] = network_dns[i] | dns[i];
        gateway[i] = network_gateway[i] | gateway[i];
        subnet[i] = network_subnet[i] | subnet[i];
    }
    isMyIpAddId = network["isMyIpAddId"] | true;
    inPort = network["inPort"] | 50000;
    outPort = network["outPort"] | 50100;
    isOutPortAddId = network["isOutPortAddId"] | true;
    JsonArray network_mac = network["mac"];
    for (i = 0; i < 6; i++) {
        mac[i] = network_mac[i] | mac[i];
    }
    isMacAddId = network["isMacAddId"] | true;
    bootedMsgEnable = network["bootedMsgEnable"] | true;
    isDestIpSet = network["canSendMsgBeforeDestIp"] | false;

    // Alarm and Report
    JsonObject alarmAndReport = doc["alarmAndReport"];
    JsonArray alarmAndReport_reportBUSY = alarmAndReport["reportBUSY"];
    JsonArray alarmAndReport_reportFLAG = alarmAndReport["reportFLAG"];
    JsonArray alarmAndReport_reportHiZ = alarmAndReport["reportHiZ"];
    JsonArray alarmAndReport_reportHomeSwStatus = alarmAndReport["reportHomeSwStatus"];
    JsonArray alarmAndReport_reportDir = alarmAndReport["reportDir"];
    JsonArray alarmAndReport_reportMotorStatus = alarmAndReport["reportMotorStatus"];
    JsonArray alarmAndReport_reportSwEvn = alarmAndReport["reportSwEvn"];
    JsonArray alarmAndReport_reportCommandError = alarmAndReport["reportCommandError"];
    JsonArray alarmAndReport_reportUVLO = alarmAndReport["reportUVLO"];
    JsonArray alarmAndReport_reportThermalStatus = alarmAndReport["reportThermalStatus"];
    JsonArray alarmAndReport_reportOCD = alarmAndReport["reportOCD"];
    JsonArray alarmAndReport_reportStall = alarmAndReport["reportStall"];
    JsonArray alarmAndReport_reportLimitSwStatus = alarmAndReport["reportLimitSwStatus"];
    JsonArray alarmAndReport_OCThreshold = alarmAndReport["OCThreshold"];
    for (i = 0; i < NUM_OF_MOTOR; i++)
    {
        reportBUSY[i] = alarmAndReport_reportBUSY[i] | false;
        reportFLAG[i] = alarmAndReport_reportFLAG[i] | false;
        reportHiZ[i] = alarmAndReport_reportHiZ[i] | false;
        reportHomeSwStatus[i] = alarmAndReport_reportHomeSwStatus[i] | false;
        reportDir[i] = alarmAndReport_reportDir[i] | false;
        reportMotorStatus[i] = alarmAndReport_reportMotorStatus[i] | false;
        reportSwEvn[i] = alarmAndReport_reportSwEvn[i] | false;
        reportCommandError[i] = alarmAndReport_reportCommandError[i] | true;
        reportUVLO[i] = alarmAndReport_reportUVLO[i] | true;
        reportThermalStatus[i] = alarmAndReport_reportThermalStatus[i] | true;
        reportOCD[i] = alarmAndReport_reportOCD[i] | true;
        reportStall[i] = alarmAndReport_reportStall[i] | true;
        reportLimitSwStatus[i] = alarmAndReport_reportLimitSwStatus[i] | false;
        overCurrentThreshold[i] = alarmAndReport_OCThreshold[i] | 15;
    }

    // Driver settings
    JsonObject driverSettings = doc["driverSettings"];
    JsonArray driverSettings_stepMode = driverSettings["stepMode"];
    JsonArray driverSettings_homeSwMode = driverSettings["homeSwMode"];
    JsonArray driverSettings_limitSwMode = driverSettings["limitSwMode"];
    JsonArray driverSettings_isCurrentMode = driverSettings["isCurrentMode"];
    JsonArray driverSettings_slewRate = driverSettings["slewRate"];
    JsonArray driverSettings_electromagnetBrakeEnable = driverSettings["electromagnetBrakeEnable"];
    uint16_t slewRateVal[6] = { SR_114V_us, SR_220V_us, SR_400V_us, SR_520V_us, SR_790V_us, SR_980V_us };
    for (i = 0; i < NUM_OF_MOTOR; i++) {
        microStepMode[i] = driverSettings_stepMode[i] | STEP_SEL_1_128;
        homeSwMode[i] = driverSettings_homeSwMode[i] | true; // true: SW_USER, false: SW_HARDSTOP
        limitSwMode[i] = driverSettings_limitSwMode[i] | true;
        isCurrentMode[i] = driverSettings_isCurrentMode[i] | false;
        slewRateNum[i] = constrain((driverSettings_slewRate[i] | 5), 0, 5); // default SR_980V_us
        slewRate[i] = slewRateVal[slewRateNum[i]];
        electromagnetBrakeEnable[i] = driverSettings_electromagnetBrakeEnable[i] | false;
    }

    // Speed profile
    JsonObject speedProfile = doc["speedProfile"];
    JsonArray speedProfile_acc = speedProfile["acc"];
    JsonArray speedProfile_dec = speedProfile["dec"];
    JsonArray speedProfile_maxSpeed = speedProfile["maxSpeed"];
    JsonArray speedProfile_fullStepSpeed = speedProfile["fullStepSpeed"];
    for (i = 0; i < NUM_OF_MOTOR; i++) {
        acc[i] = speedProfile_acc[i] | 1000.;
        dec[i] = speedProfile_dec[i] | 1000.;
        maxSpeed[i] = speedProfile_maxSpeed[i] | 650.;
        fullStepSpeed[i] = speedProfile_fullStepSpeed[i] | 15610.;
    }
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

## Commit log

2020-12-18 Added hardware design files.
    [brakeBoard.brd, brakeBoard.sch, step400_r1.brd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]
2020-12-20 Added BOM lists
    [brakeBoard_BOM.csv, step400_r1_BOM.csv]
2021-01-25 Added config tool files
    [config.txt]
2021-02-17 electromagnet brake update
2021-02-25 homing functions
    [config.txt]
2021-02-26 Homing updates
2021-02-26 added new items to the configTool index.html
    [config.txt]
2021-02-26 updated new config items
    [config.txt]
2021-03-01 update config and error
    [config.txt]
2021-03-03 Update Arduino sketch folder
2021-03-03 Added schematics PDFs
2021-03-09 Added prototype version PCB support
2021-03-09 Arduino sketch folder update
2021-03-12 Fixed setTval bug
    [config.txt]
2021-04-10 Fixed a problem of starting up with a current mode.
    Fixed a problem that a request to start in a current drive mode in the configTool is ignored.
    Also fixed some typos.
    [main.cpp]
2021-04-15 updated the Arduino sketch directory
2021-04-28 Fixed loading myIp, outPort and mac when the DIP sw changed.
    [main.cpp]
2021-05-03 Updated the Arduino sketch folder
2021-05-09 Fixed some typos in the hardware inspection sketch
    [hardwareTestSketch.ino]
2021-06-28 Update the Ponoor PowerSTEP01 Library version number.
2021-11-24 configTool update and some bugfixes for minSpeed/lowSpeedOptimization
    [main.cpp]
2021-12-02 added /resetDevice and remove resetDev command
    [main.cpp]
2021-12-04 confifgTool updating (not completed yet)
    [config.txt]
2021-12-08 Update setElPos arguments and bug fixes for loading config
    [main.cpp]
2021-12-08 updated Arduino sketch folder
2022-02-13 check the homing status for motion/stop commands
2022-02-14 Arduino sketch folder sync
2022-02-14 only `/run` can interrupt a homing among motion commands.
    Other motion commands will be ignored during a homing.
2022-03-03 Fixed the incorrect `/getHomeSw` response.
    [main.cpp]
2024-03-01 Added the LED test for hardware test firmware
    Also convert the Arduino project to the platformIO project
2024-03-04 Fixed some alarms during the test.
    [main.cpp]
2024-03-07 Remove old firmware directories.
    [step400_r1_BOM.csv, step400_r1_BOM.xlsx]
2024-03-07 BOM update for r1.0.1
    [step400_r1.0.0_BOM.csv, step400_r1.0.1_BOM.csv]
2026-10-09 Add KiCad import of STEP400 r1 and update README
    - Import the EAGLE r1 schematic and board into KiCad 10 (hardware/step400_r1/)
    as a reference for the next hardware revision
    - Fix schematic connectivity lost in the import (R15/R16 back on 3.3V)
    - Merge inner layer In14 into In2 and reduce the stackup to 4 layers
    - Add a project footprint library (step400_r1.pretty) exported from the
    board and verified against the EAGLE packages
    - Rewrite README: current documentation, firmware repository, config tool,
    examples, and the KiCad migration status
    - Ignore KiCad lock, backup, cache and local settings files
    Claude-Session: https://claud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

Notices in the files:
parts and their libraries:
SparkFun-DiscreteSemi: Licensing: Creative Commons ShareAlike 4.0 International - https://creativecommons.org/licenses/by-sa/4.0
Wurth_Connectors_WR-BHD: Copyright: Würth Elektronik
